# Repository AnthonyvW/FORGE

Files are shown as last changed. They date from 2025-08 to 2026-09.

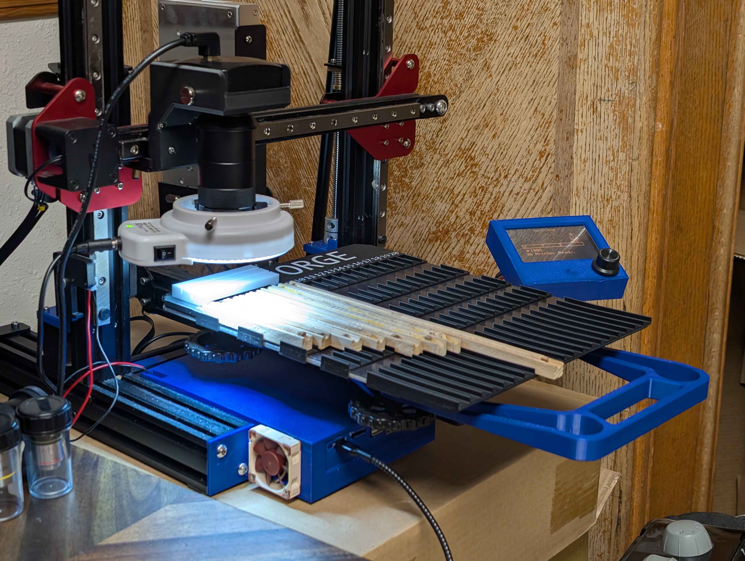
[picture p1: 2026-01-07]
media/DeveloperForge.jpg

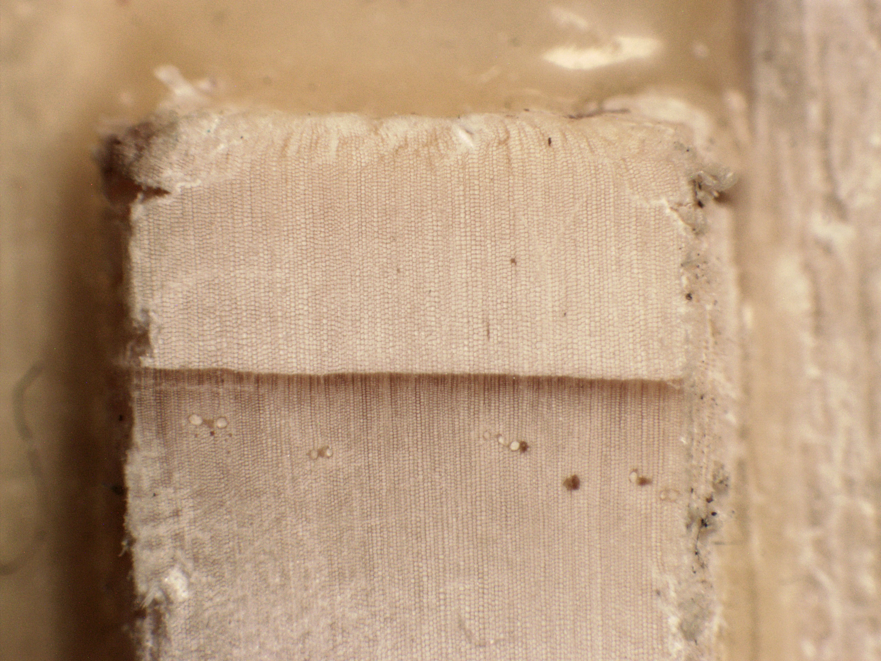
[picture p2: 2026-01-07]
media/WoodExample.jpg

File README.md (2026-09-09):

# FieldWeave - Low Cost Gigapixel Imaging Machine








FieldWeave is an open-source, gigapixel imaging system built on a modified off-the-shelf 3D printer. It automates sample capture, focus stacking, and DPI calibration, producing high resolution images across a wide range of fields. See it in action on the [FieldWeave website](https://www.fieldweave.com), which includes an interactive gallery for browsing full-resolution scans.

**If FieldWeave is useful to you, please consider giving it a star and supporting its development. See [Support FieldWeave](#support-fieldweave) below.**

## Features

* **Automated Scanning**: Utilizes 3D printer mechanics for precise, repeatable sample movement.
* **High-Resolution Imaging**: Captures gigapixel images across dendrochronology, geology, life sciences, museum, manufacturing, and forensic use cases.
* **Focus Stacking**: Built-in stacking via FocusWeave.
* **Automated DPI Calibration**: Calibrates scan resolution automatically against a compatible micrometer slide.
* **Modular Design**: Easily adaptable to different sample types, lenses, and imaging requirements.

## Examples

### [Browse the full gallery at fieldweave.com/gallery](https://www.fieldweave.com/gallery)

<table>
  <tr>
    <td width="33%">
      <a href="https://www.fieldweave.com/gallery/image/cross-section-1">
        Cross section of a black spruce tree core, click to view full resolution on the FieldWeave gallery
      </a>
    </td>
    <td width="33%">
      <a href="https://www.fieldweave.com/gallery/image/western-hemlock-core">
        Western hemlock tree core, click to view full resolution on the FieldWeave gallery
      </a>
    </td>
    <td width="33%">
      <a href="https://www.fieldweave.com/gallery/image/basswood-stem-cs">
        Cross section of a basswood stem, click to view full resolution on the FieldWeave gallery
      </a>
    </td>
  </tr>
	<tr>
    <th>Black spruce tree core cross section</th>
    <th>Western hemlock tree core</th>
    <th>Basswood stem cross section</th>
	</tr>
  <tr>
    <td width="33%">
      <a href="https://www.fieldweave.com/gallery/image/rusty-7-16-drill-bit">
        A rusty 7/16 drill bit, click to view full resolution on the FieldWeave gallery
      </a>
    </td>
    <td width="33%">
      <a href="https://www.fieldweave.com/gallery/image/us-dime-back">
        Back of a US dime, click to view full resolution on the FieldWeave gallery
      </a>
    </td>
    <td width="33%">
      <a href="https://www.fieldweave.com/gallery/image/9mm-1">
        Spent 9mm bullet casing, click to view full resolution on the FieldWeave gallery
      </a>
    </td>
  </tr>
	<tr>
    <th>A rusty 7/16 drill bit</th>
    <th>Back of a US dime</th>
    <th>Spent 9mm bullet casing</th>
	</tr>
</table>

## Support FieldWeave

FieldWeave is free and GPL-licensed, and stays that way through community support. If it's useful to your lab, workflow, or project, consider chipping in. Funding goes directly toward hardware, testing, and development time.

* **GitHub Sponsors**: [github.com/sponsors/AnthonyvW](https://github.com/sponsors/AnthonyvW)
* **Ko-fi**: [ko-fi.com/procerand](https://ko-fi.com/procerand)

Have a specific feature your lab needs? [Commission a feature](https://www.fieldweave.com/contact) it gets built for you and becomes available to everyone.

## Getting Started

### Prerequisites

* **Hardware**: A [compatible 3D printer](#3d-printer-compatibility) modified for imaging purposes, a light, and a [compatible camera](#confirmed-compatible-cameras). The 3D printer may also require an additional cable to connect your PC to the printer. Note that this modification will likely void the warranty if you disconnect any cables, so test the 3D printer to ensure the motion system works before doing this.
  * For the light I recommend using the [Amscope 144 led ring light](https://www.amazon.com/dp/B00JZJO7YC). If you use this, make sure to 3D print the light pads to prevent scratching the lens.
  * If using an Amscope camera, I highly recommend using this ([100x Microscope Lens for Raspberry Pi](https://www.amazon.com/100X-Microscope-Lens-Magnification-Compatible/dp/B0C1CC79TX)) industrial lens as it provides minimal distortion around the edges.
  * Not required, but is recommended is a thumbscrew for holding the camera in place. I use thumbscrews from [this 16 piece set](https://www.amazon.com/dp/B0DQPM68KJ) from Amazon.
  * For the automated DPI calibration to work, a compatible micrometer calibration slide is required. It is confirmed to work with the [Amscope MR400 Stage Micrometer Calibration Slide with 4-Scales](https://amscope.com/products/mr400). I am interested in adding support for additional scales.
  * If you do not have access to a 3D printer capable of printing in at least 2 colors and wish to image tree core samples, then a roll of red electrical tape to denote the center of slots.
* **High Magnification Imaging Hardware**
  * Note: This is a more expensive version that achieves far greater magnification than most other setups, however it requires additional modifications. Instead of using the 100x lens listed above, use the following parts instead for the optics.
  * To successfully do this version with 10x objective it will require upgrading the leadscrews to [350mm Tr8X2 2mm lead](https://www.amazon.com/dp/B095M8SQQV?th=1) with the appropriate [anti backlash nuts](https://www.amazon.com/dp/B085GGMCVG?th=1)
  * For the tube lense I recommend using the [Raynox DCR 250 Lens](https://www.amazon.com/Raynox-DCR-250-Super-Macro-Snap/dp/B000A1SZ2Y/) as there are 3D models present that use that.
  * [M49 to RMS Adapter](https://www.amazon.com/dp/B0FHN8FQ7T) for connecting the microscope objective to the tube lens
  * [C Mount to M42 Adapter](https://www.amazon.com/dp/B0812QPHWN) for connecting the camera to the high magnification setup.
  * For the high magnification setup, 1/4" thumbscrews are required to hold the camera in place. I use thumbscrews from [this 16 piece set](https://www.amazon.com/dp/B0DQPM68KJ) from Amazon.
  * For the microscope objective I recommend either the [Amscope 4x Metallurgic objective](https://amscope.com/products/pl4x-inf-v300) or the [Amscope 10x metallurgic objective](https://amscope.com/products/pl10x-inf-v300) both objectives are infinity plan achromatic objectives. Using anything above 10x is not recommended due to the depth of field becoming shallower than what the machine is capable of moving.
  * Due to the depth of the holes on the 3D printed parts I recommend getting a set of longer than usual metric hex keys so you can screw everything in properly. I use [this set.](https://www.amazon.com/dp/B0000CBJDV) 
* **Software**: Python 3.x and Git
* **Operating System**: Linux, Windows 10, or Windows 11

## Printer Modification

Before using FieldWeave, your 3D printer must be modified to mount the camera system in place of the print head.

### Required Printed Parts

Before modifying your printer, you must 3D print the following components:

- **Camera Mount** - Ender 3 Camera Mount.3mf – Attaches to the existing print head carriage  
- **High Resolution Camera Mount Files** - high_magnification folder
  * These are only for if you are going with the high magnification version of FieldWeave.
  * MicroscopeObjectiveMount.3mf - Attaches to print head carriage
  * Light Baffles.3mf - Insert to objective mount after screwing the mount in.
  * Amscope Mount.3mf - Attaches to the print head carriage to hold camera in place
  * RaynoxRingLightBuffer.3mf - Use if using the amscope ring light with it. You will need 3 of these. These help hold the ring light still.
- **Z-Axis Spacer** - ZAxisSpacer.3mf – Raises the Z-axis endstop to accommodate the new camera height  
    - If you are proficient with working with electronics, I suggest replacing the Z axis end stop wires with longer ones instead and mounting the Z axis limit switch higher.

> files for these parts will be provided in the `hardware/` folder of this repository.

### Optional Printed Parts
- **Calibration Slide Tray** - If using a micrometer calibration slide, this tray holds it stationary on the bed of the machine while providing a solid colored background.
- **Sample Clips** – Secure tree core samples to the print bed without manual alignment
    - SampleHolderEnd.3mf
    - SampleHolderFooter.3mf - If printing the multicolor version ensure that all the tick marks are printed in a red filament.
    - SampleHolderMiddle.3mf - You will need 3 of these. I suggest printing one of these off and ensuring that it properly fits before printing off the rest of the parts.
---

### Modification Instructions

> ! IMPORTANT ! Ensure that you have all 3D printed parts before modifying your 3D printer.

1. **Unplug 3D Printer**  
   Ensure the 3D printer is disconnected from power before working on it.

2. **Remove the Print Head**  
   Unscrew and detach the printer's hotend from the X-axis print carriage.

3. **Disconnect Wiring**  
   Carefully disconnect the hotend and heatbed wiring from the printer's control board. This prevents accidental heating or movement of the removed components.

4. **Install Camera Mount**  
   Use the print head screws to attach the printed camera mount to the same location on the print carriage where the print head was originally mounted.

5. **Insert Z-Axis Spacer**  
   Add the printed Z-axis spacer on the Z endstop, so the camera does not crash while homing.

6. **Insert sample clips**
   If you choose to use sample clips then this is the stage where you would want to slide them onto the print bed. If you printed the footer in single color you will also want to mark the center of the slots (above the slot not in the slot) with a red mark. I recommend using red electrical tape as it doesn't fade.

7. **Install Camera and Lens**  
   - Insert your digital microscope or Amscope camera into the printed mount.  
   - Screw on the imaging lens securely.  
   
8. **Install Light**  
   Install the light you will be using with FieldWeave. 
   > If using the Amscope ring light, place the light pads onto the metal tips of the screws that hold the light in place before putting the light on the lens.

9. **Plug Everything in**  
   - Plug the 3D printer back into the wall
   - Plug the 3D printer into your computer via USB for motion control.  
   - Plug in the camera using its USB interface for image capture.
   - Plug in the Light

10. **Done**

### Installation

Prerequisites\. Ensure you have the latest version of python installed, and you have git installed.

> Python : https://www.python.org/downloads/  
> Git : https://git-scm.com/downloads

1\. Clone the repository:

   ```bash
   git clone https://github.com/AnthonyvW/FieldWeave.git
   cd FieldWeave
   ```

2\. Install the required Python packages:

  ```bash
  pip install -r requirements.txt
  ```

3\.1\. Download the Amscope SDK for your camera at https://amscope.com/pages/software-downloads if you are on mac or linux, download the windows version as it includes the files for those operating systems there.

3\.2\. Move the downloaded zipped folder into 3rd_party_imports

4\. Run the install scripts:

  Windows
  ```bash
  windows_install.bat
  ```
  Linux
  ```bash
  ./ubuntu_install.sh
  ```
5\. Start FieldWeave

  Windows
  ```bash
  windows_start.bat
  ```
  Linux
  ```bash
  ./ubuntu_start.sh
  ```

---
## Confirmed Compatible Cameras
FieldWeave supports USB cameras through a modular driver architecture.

| Camera Model | Notes |
|---|---|
| Amscope MU500 | Fully tested and supported  |
| Amscope MU1000 | Fully tested, the automatic DPI calibration might not work due to it being tested at a lower resolution than this camera's max resolution |
| Amscope MU1000 HS | Fully tested, the automatic DPI calibration might not work due to it being tested at a lower resolution than this camera's max resolution |
| Generic USB Camera | This was tested with 2 different USB cameras and is supported  |
| Other Amscope Cameras | They should work, but are not tested. Camera mount might need to be modfied for them to fit. |

⚠️ Amscope's SDK on their website is currently out of date as of 8/15/2026. If you contact Amscope support an up to date version can be provided. The SDK version I use is Version: 59.30149.20251130

### Adding Support for New Cameras

Users are encouraged to contribute new camera interfaces by implementing the FieldWeave camera interface and submitting them as pull requests.

If your camera is not currently supported or you would like to contribute an interfaces, please open an issue or submit a pull request.

Due to the complexity of hardware integration, especially with cameras requiring proprietary APIs or SDKs full support often requires physical access to the device for development and testing. If you would like me to implement support for your camera, please be prepared to ship the device or provide access to equivalent hardware.

Alternatively, contributions of driver implementations with thorough documentation and test instructions are highly appreciated.

## 3D Printer Compatibility

FieldWeave is designed to run on 3D printers using **Marlin firmware**, which supports standard G-code over USB serial. Compatibility with other firmware types varies and may require additional configuration or is not currently supported.

> Not sure if your 3D printer will work? Plug your printer into your computer via USB, and then start FieldWeave. If the printer homes then it is compatible with FieldWeave.

## Confirmed Compatible Printers

| Printer Model | Firmware | Build Volume (mm) | Notes |
|---|---|---|---|
| Ender 3 v1 | Marlin | 220 × 220 × 250 | Fully tested and supported. It is highly recommended that you use the official linear rail upgrade kit provided by Creality for the increased camera stability. |
| Creality CR-10S Pro v2  | Marlin | 300 × 300 × 400 | Fully tested; camera mount file not available. |
| Anycubic Kobra Max v1 | Marlin | 400 × 400 × 450 | Fully tested; camera mount file not available. |
---

> Want to help verify compatibility with other printers, firmware, or cameras?  
> [Open an issue](https://github.com/AnthonyvW/FieldWeave/issues) with your setup details and test results!

## Confirmed Incompatible Printers

| Printer Model | Build Volume (mm) | Notes |
|---|---|---|
| Bambulab A1 | 220 × 220 × 250 | Properietary Firmware, cannot send gcode directly to it  |

---

## Contributing

Contributions are welcome! Please fork the repository and submit a pull request with your enhancements. For major changes, open an issue first to discuss your proposed modifications.

Not able to contribute code? Financial support is just as valuable; see [Support FieldWeave](#support-fieldweave) above ([GitHub Sponsors](https://github.com/sponsors/AnthonyvW) / [Ko-fi](https://ko-fi.com/procerand)).

## Troubleshooting

**Camera freezes when taking pictures**
- Sometimes the serial drivers conflict with the camera drivers, to fix this, plug in the camera and the 3D printer into two different sides of the computer. This forces them to be on different usb controllers which fixes any conflicts they might have.

**My Camera isn't found**
- Make sure that you have the camera drivers installed. If your camera was previously found, but is no longer found, try unplugging it and plugging it back in and ensuring the OS detects that it is plugged in as it might be a bad cable.

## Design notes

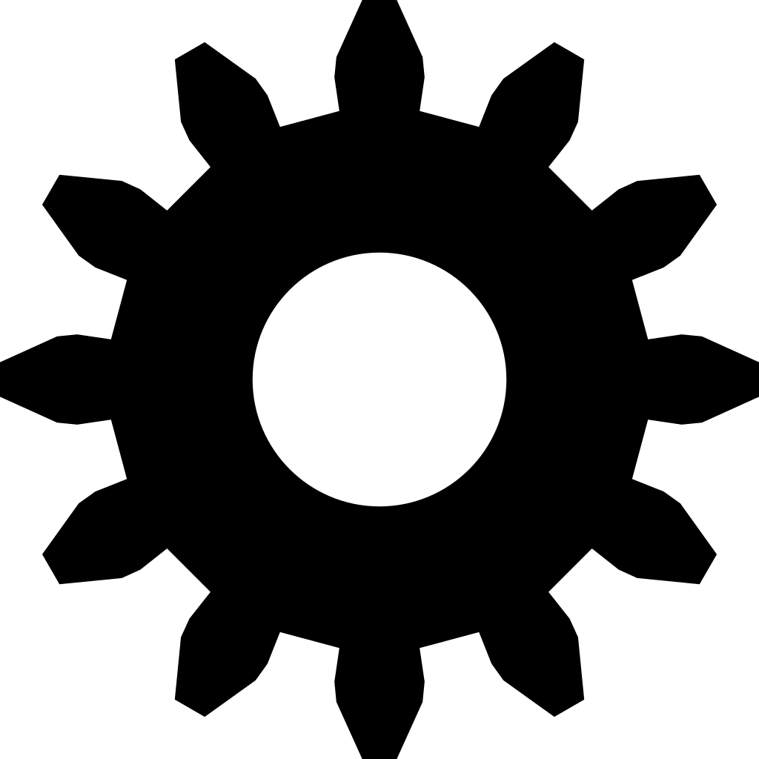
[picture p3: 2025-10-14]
assets/gear.png

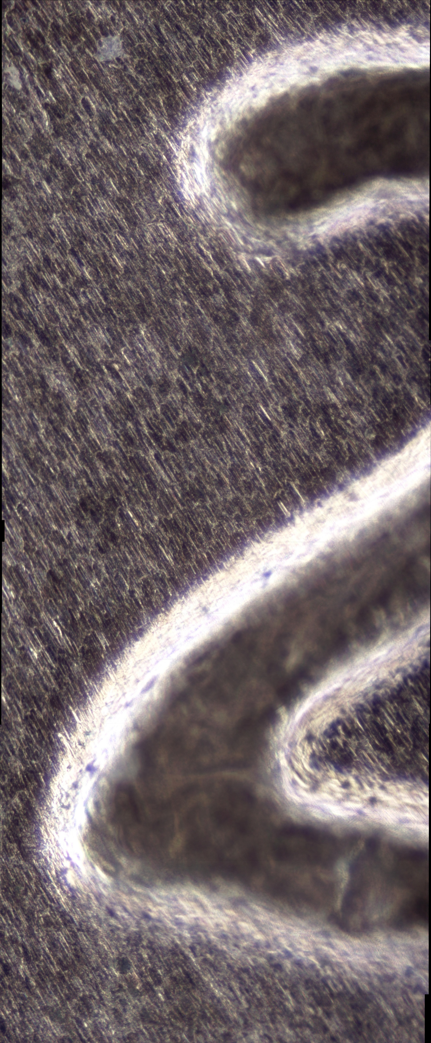
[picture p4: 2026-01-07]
media/2Penny.jpg

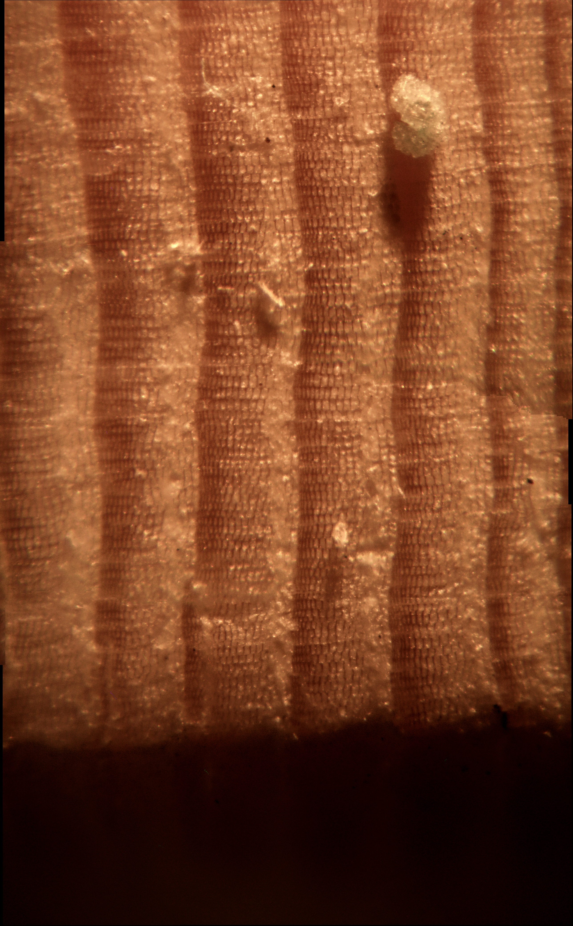
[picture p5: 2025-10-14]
media/Dust.jpg

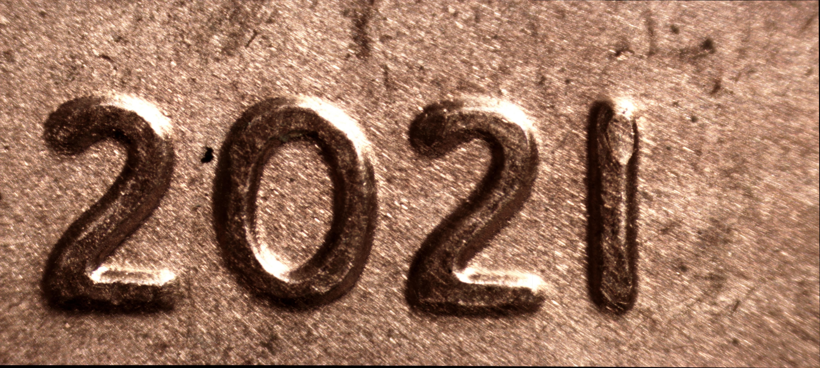
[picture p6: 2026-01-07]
media/penny.jpg

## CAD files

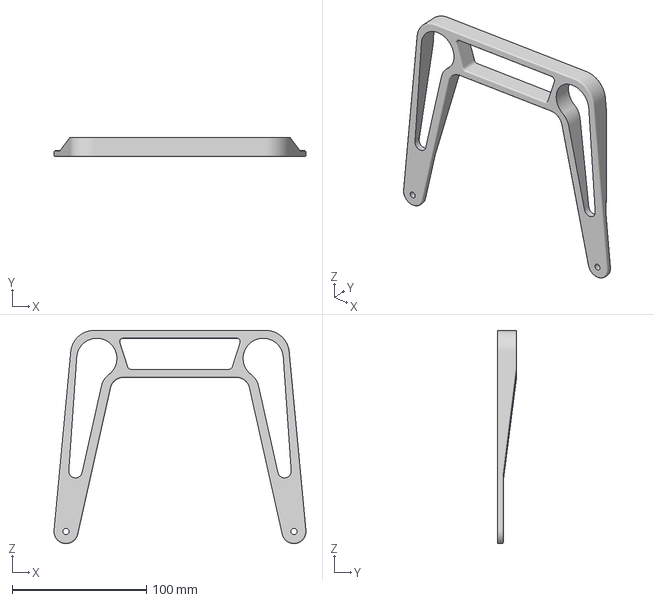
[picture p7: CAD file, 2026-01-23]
hardware/handle.3mf
187.9 x 14.5 x 159.0 mm

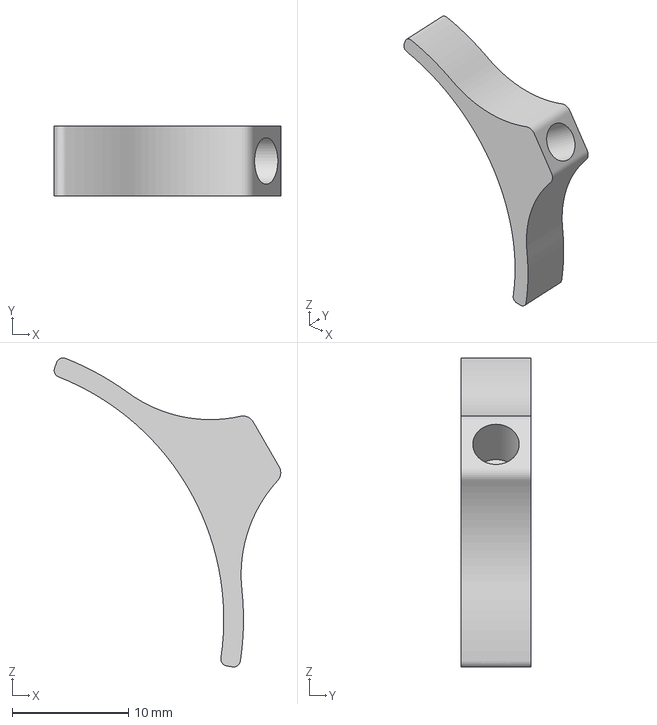
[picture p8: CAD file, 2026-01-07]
hardware/high_magnification/RaynoxRingLightBuffer.3mf
19.5 x 6.00 x 26.6 mm

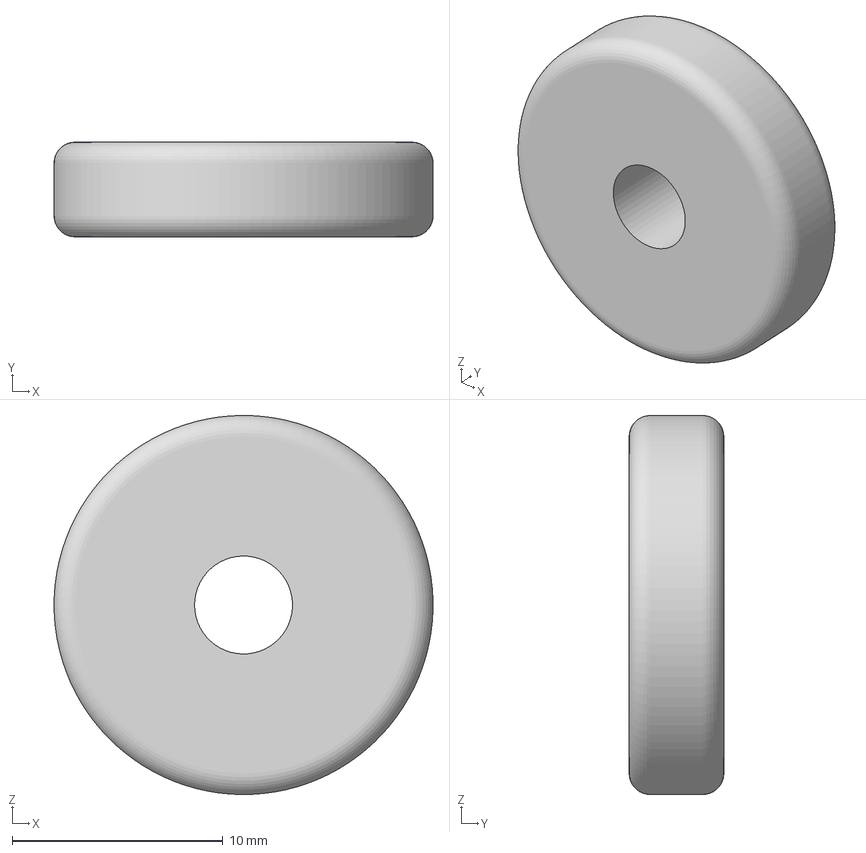
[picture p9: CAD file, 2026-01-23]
hardware/bedspacer.3mf
18.0 x 4.50 x 18.0 mm

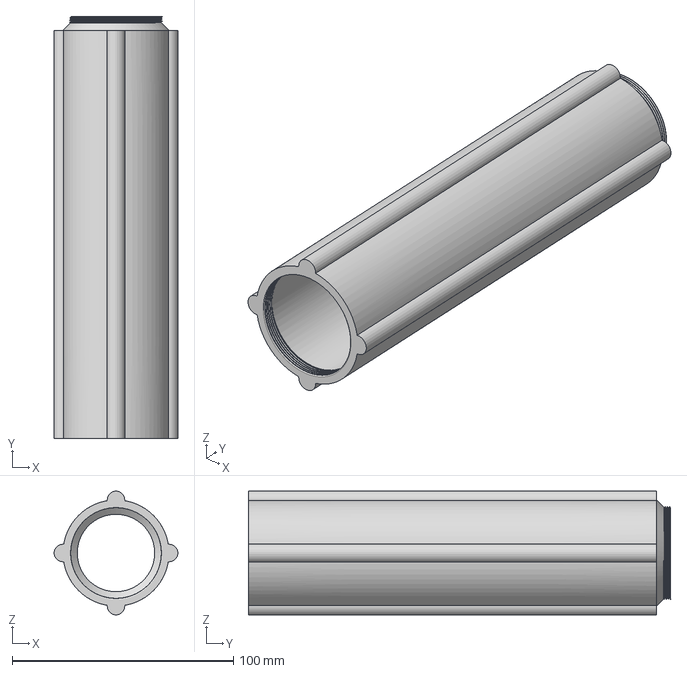
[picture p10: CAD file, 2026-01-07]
hardware/high_magnification/200mmExtensionTube.3mf
55.9 x 190.9 x 55.9 mm

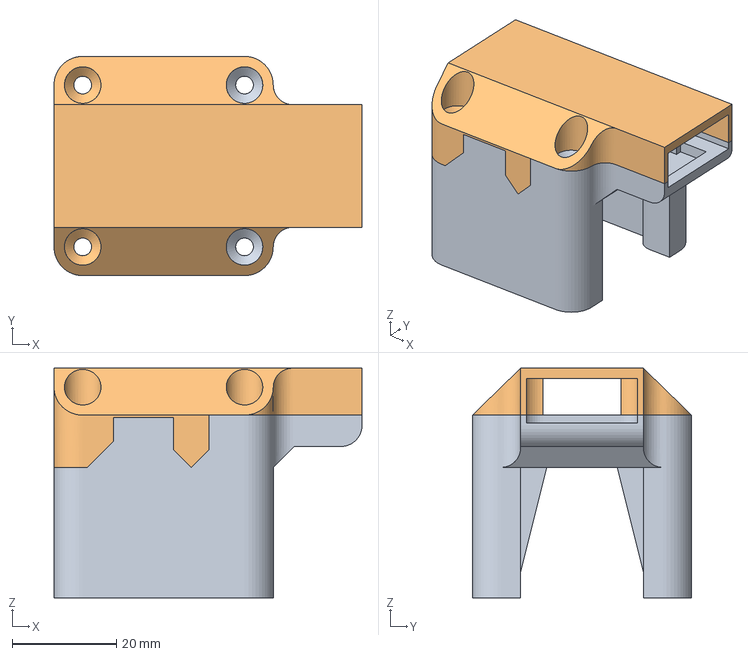
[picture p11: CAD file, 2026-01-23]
hardware/X Axis Motor Cover.3mf
59.0 x 42.0 x 44.0 mm

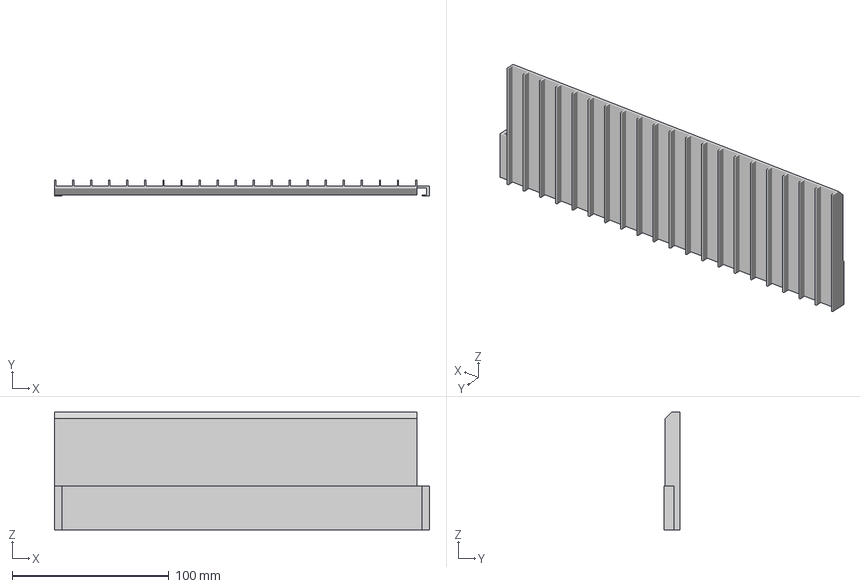
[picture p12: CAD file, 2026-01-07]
hardware/SampleHolderEnd.3mf
239.0 x 10.3 x 75.0 mm

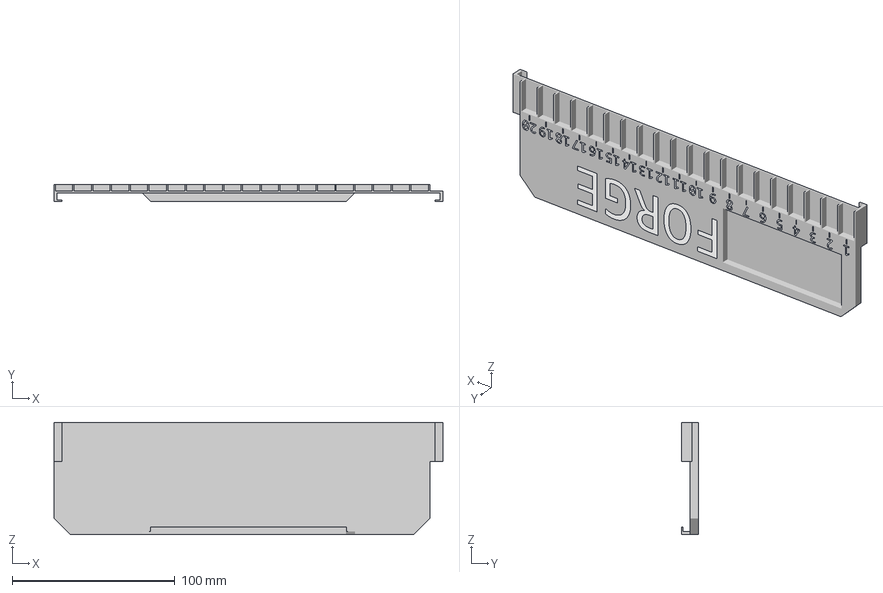
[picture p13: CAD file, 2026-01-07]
hardware/SampleHolderFooterMultiMaterial.3mf
239.0 x 10.3 x 69.0 mm
SampleHolderFooter

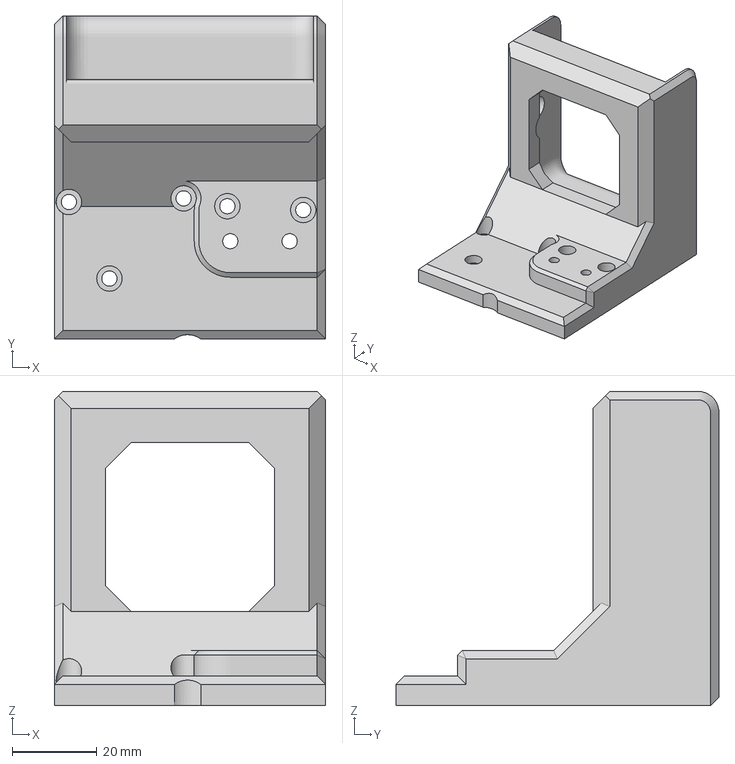
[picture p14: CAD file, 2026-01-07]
hardware/Ender 3 Camera Mount.3mf
64.0 x 76.1 x 74.1 mm

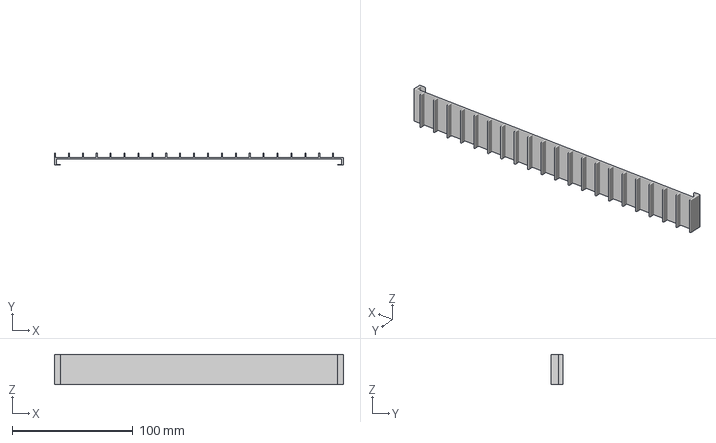
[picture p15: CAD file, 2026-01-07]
hardware/SampleHolderMiddle.3mf
239.0 x 10.3 x 25.0 mm

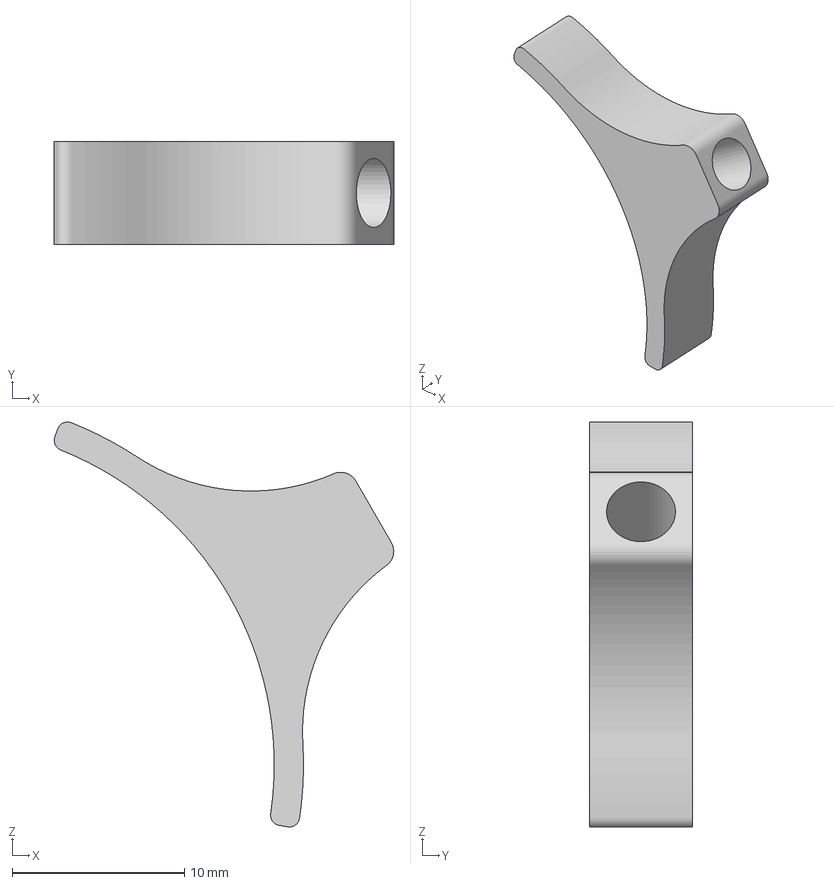
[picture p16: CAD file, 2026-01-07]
hardware/IndustrialLensRingLightPad.3mf
19.7 x 6.00 x 23.5 mm

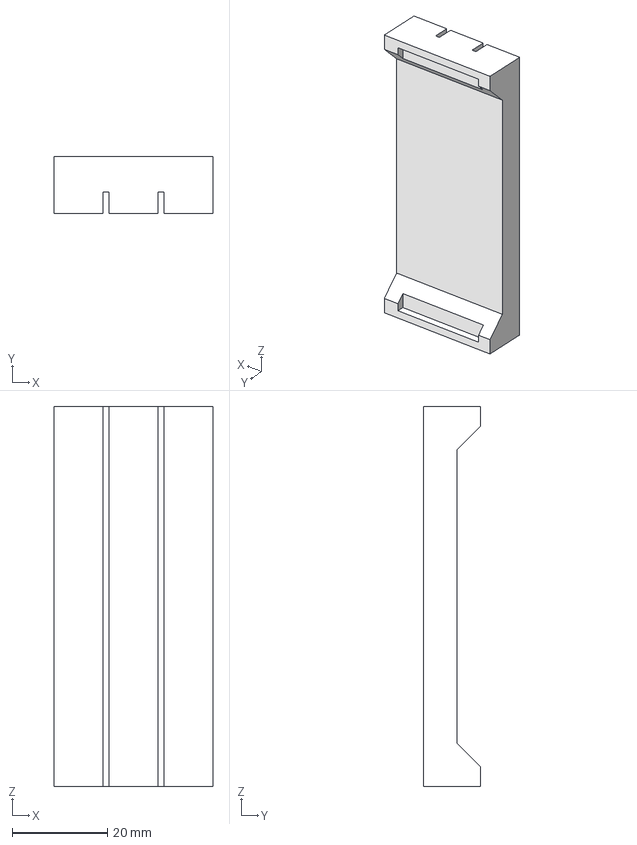
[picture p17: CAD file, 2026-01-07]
hardware/Calibration Slide Holder.3mf
33.3 x 12.0 x 79.6 mm

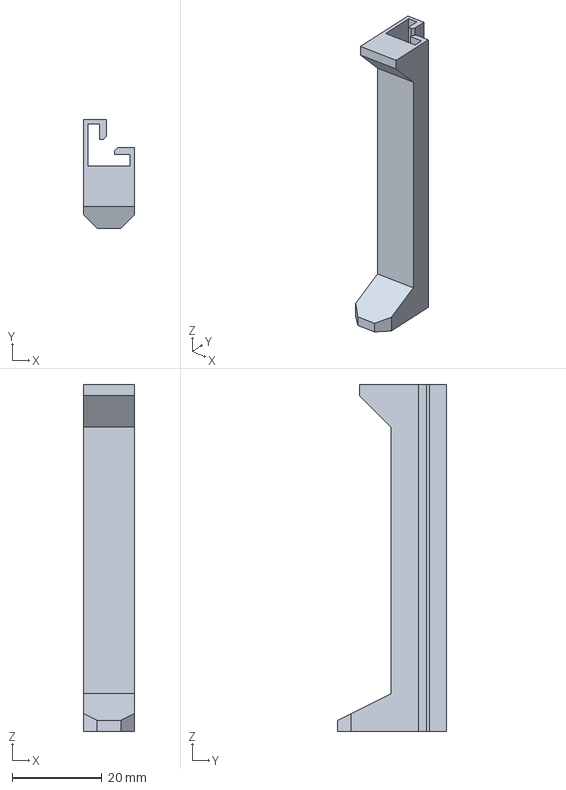
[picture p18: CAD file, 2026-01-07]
hardware/ZAxisSpacer.3mf
11.4 x 24.3 x 77.5 mm

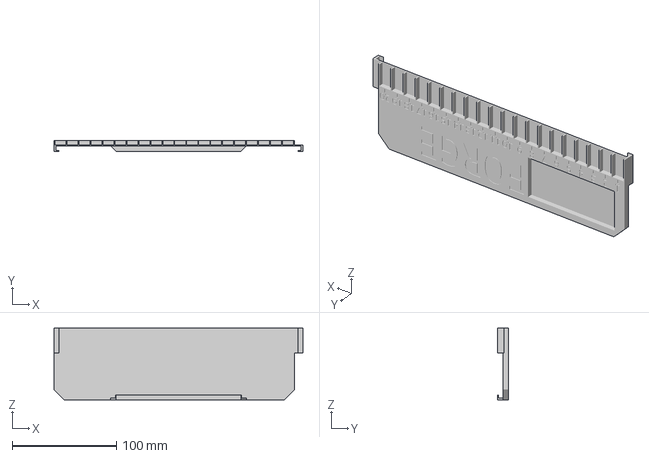
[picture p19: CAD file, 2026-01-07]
hardware/SampleHolderFooterSingleColor.3mf
239.0 x 10.3 x 69.0 mm

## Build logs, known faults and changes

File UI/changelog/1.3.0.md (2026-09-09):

# What's Changed
---
FieldWeave now has a changelog! It will display after every update, if you miss it and want to view it again, you can do so in the about page in the settings by pressing the view changelog button. In addition, it now has released based updates, this allows there to be a changelog that can be viewed ahead of time. The most notable change in this update is the addition of the measurement tab allowing you to measure things in FieldWeave. This also includes manual DPI calibration built in so you no longer have to go to an external program to obtain the DPI of a given image. 

In the next major update, you can look forward to an overhaul of the focus stacking allowing you to use other programs, improvements to time estimates, and the long awaited built in image stitching for tree core samples. 

If you come across any bugs while using FieldWeave, have feedback, or just want to request new features, please send them to <contact@FieldWeave.com> or open an issue on Github at <https://github.com/AnthonyvW/FieldWeave/issues/new>

# New Features & Improvements
---
- Added patch number to versioning scheme
- Added patch notes pop up
- Added button to view patch notes in the about page in settings
- Can now use the arrow keys to navigate when zoomed in
- Focus stacked images now preserve image metadata
- Added Measurement Tab
    - Added image viewer capable of handling terapixel images
    - Added manual DPI calibration
    - Added 34 measurement types
    - Added 4 annotation options
- Added manual DPI calibration path in the DPI calibration tab. This is also now a fallback in case the automatic DPI calibration fails.
- Added way to cancel the DPI calibration and return to the calibration tab from the DPI calibration tab.
- Added way to cancel the camera space calibration and return to the calibration tab from the camera space calibration tab.
- If the DPI calibration routine or the automatic DPI calibration fails, it will no longer set the DPI.
- All automation routines now have a button to open the output folder when running.
- Added github link on about page.
- Switched to release based updates

# Bugfixes
---
- Version field in config files now successfully migrates and is saved
- Fixed the post processing manager creating a redundant config
- While developing it will no longer warn about failing to update.
- Toasts no longer throw errors if you close the program while one is active.
- Fixed Amscope cameras not saving all camera metadata.
- Fixed Tiff writer not saving metadata.
- Camera metadata now saves to the proper metadata fields.
- Fixed issue where occasionally when doing area scan imaging an image from the previous stack would end up in the next stack.

# Known bugs
---
- Automatic camera calibration fails when using a resolution of 5120x3840
- Automatic DPI calibration fails if slide isn't perfectly straight
- Automatic DPI calibration tends to fail when using high resolution imagery
- Logs tab becomes extremely laggy on long runs.

# Support FieldWeave
---
FieldWeave is free and open source, and stays that way through community support. If it's useful to your lab, workflow, or project, consider chipping in. Funding goes directly toward hardware, testing, and development time.

* **GitHub Sponsors**: [github.com/sponsors/AnthonyvW](https://github.com/sponsors/AnthonyvW)
* **Ko-fi**: [ko-fi.com/procerand](https://ko-fi.com/procerand)

Have a specific feature your lab needs or just want to give feedback? [Contact us through the contact form](https://www.fieldweave.com/contact) or email us at <contact@fieldweave.com>

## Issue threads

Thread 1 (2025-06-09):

GUI polish to match feature parity with TRIM

AnthonyvW, 2025-06-09:
This issue tracks the implementation of features required for FORGE to reach functional parity with the legacy TRIM software. These are essential usability improvements needed for the v1.0 release.

**Tasks:**

- [x] Add ability to save, load, and export settings from the GUI
- [x] Add option to set custom save path for images
- [x] Add field to manually enter core length
- [x] Add option to set filename prefix
- [x] Add option to choose image format (PNG, JPEG, TIFF)
- [ ] Add UI control to customize shift length
- [x] Add UI for modifying camera settings (exposure, gain, etc.)

Closed 2025-08-21.

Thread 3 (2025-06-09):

Design 3D printable core holders for easy alignment

AnthonyvW, 2025-06-09:
Currently, it's a bit of pain making sure the sample is straight enough, so having 3D printed core holders would make it super easy to make sure everything is aligned properly.

Closed 2025-08-21.

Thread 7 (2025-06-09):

Clean up GUI

AnthonyvW, 2025-06-09:
Right now, it is the definition of programmer UI. This issue will track when it finally doesn't look terrible.

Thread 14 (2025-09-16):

Cannot fully image 20th slot of Ender 3 Guides

AnthonyvW, 2025-09-16:
The 20th slot on the Ender 3 is half outside of the 235mm area that the ender 3 allows moving the X axis on, as such the guides need to be modified to allow imaging that slot.

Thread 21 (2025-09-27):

Modular Z axis spacer

AnthonyvW, 2025-09-27:
The Z axis needs to be different heights depending on lenses used and printer used, as such a modular spacer would be appreciated. Preferably one that does not require disassembling the printer like the current spacer does.

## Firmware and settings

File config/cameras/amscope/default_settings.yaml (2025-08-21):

# Camera configuration (values + ranges). Ranges mirror settings.py.
auto_expo: false

# Auto Exposure Target
exposure: 16
exposure_min: 16
exposure_max: 220

# White balance temperature
temp: 10794
temp_min: 2000
temp_max: 15000

# White balance tint
tint: 925
tint_min: 200
tint_max: 2500

# Level ranges (RGBA). Min/max apply per channel.
levelrange_low: [0, 0, 0, 0]
levelrange_high: [255, 255, 255, 255]
levelrange_min: 0
levelrange_max: 255

contrast: 10
contrast_min: -100
contrast_max: 100

hue: 0
hue_min: -180
hue_max: 180

saturation: 45
saturation_min: 0
saturation_max: 255

brightness: -3
brightness_min: -64
brightness_max: 64

gamma: 100
gamma_min: 20
gamma_max: 180

# White balance gains (R, G, B). Min/max apply per channel.
wbgain: [0, 0, 0]
wbgain_min: -127
wbgain_max: 127

sharpening: 48
sharpening_min: 0
sharpening_max: 500

# 0/1; range is discrete but included for completeness
linear: 1
linear_min: 0
linear_max: 1

curve: Polynomial
fformat: tiff

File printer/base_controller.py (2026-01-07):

from dataclasses import dataclass
from enum import Enum
from queue import Queue
from typing import Optional, Callable, List, Dict, Iterable
import serial
import serial.tools.list_ports
import time
import queue
import threading
import re

from .models import Position
from .printerConfig import (
    PrinterSettings,
    PrinterSettingsManager
)
from forgeConfig import (
    ForgeSettings,
)

def _probe_port(port_device, baud, indicators, request=b"M115\r\n", read_window_s=10, min_lines=3):
    """
    Try to identify a Marlin-like printer on a single serial port.
    Returns (serial_connection, response_lines) on success, or (None, response_lines) on failure.
    On success, the serial connection is LEFT OPEN for the caller.
    """
    responses = []
    ser = None
    success = False
    try:
        ser = serial.Serial(
            port_device,
            baudrate=baud,
            timeout=0.25,       # slightly less chatty spin
            write_timeout=1
        )

        # Some controllers reset on open due to DTR; give them a brief window to chatter.
        start = time.time()
        quiet_since = start
        while time.time() - start < 2.0:   # ~2s settle (exits earlier if quiet)
            while ser.in_waiting:
                line = ser.readline().decode("utf-8", errors="ignore").strip()
                if line:
                    responses.append(line)
                    quiet_since = time.time()
            if time.time() - quiet_since > 0.25:
                break
            time.sleep(0.05)

        # Ask for firmware info
        ser.reset_input_buffer()
        ser.write(request)

        # Read with a firm window
        start = time.time()
        while time.time() - start < read_window_s:
            if ser.in_waiting:
                line = ser.readline().decode("utf-8", errors="ignore").strip()
                if line:
                    responses.append(line)
                    if any(ind in line for ind in indicators):
                        success = True
                        break
                    # Heuristic: enough lines + a few seconds → likely the right device
                    if len(responses) >= min_lines and time.time() - start > 3:
                        success = True
                        break
            else:
                time.sleep(0.05)

        if success:
            return ser, responses  # leave open
        else:
            return None, responses
    except Exception:
        return None, responses
    finally:
        # Only close when NOT successful
        if ser is not None and ser.is_open and not success:
            try:
                ser.close()
            except Exception:
                pass


class PrinterFault(Exception): pass
class PrinterTimeout(Exception): pass

@dataclass
class command:
    kind: str 
    value: any
    message: Optional[str] = None   
    log: bool = False

class BasePrinterController:
    CONFIG_SUBDIR = "Ender3"
    """Base class for 3D printer control"""
    def __init__(self, forgeConfig: ForgeSettings):
        self.config = PrinterSettings()
        PrinterSettingsManager.scope_dir(self.CONFIG_SUBDIR)
        self.config = PrinterSettingsManager.load(self.CONFIG_SUBDIR)

        self.position = Position(0, 0, 0) # Current position
        self.speed = self.config.step_size  # Current Speed
        self.paused = False
        self.stop_requested = False
        self.faulted = False

        self.command_queue: Queue[command] = Queue()

        # Buffer for macros when paused.
        self._front_buffer: List[command] = []
        self._front_lock = threading.Lock()
        
        # Callbacks
        self._message_listeners: List[Callable[[str, bool, command], None]] = []
        self._handlers: Dict[str, Callable[[command], None]] = {}
        
        # register built-ins
        self.register_handler("PRINTER", self._handle_printer)
        self.register_handler("MACRO", self._handle_macro)
        self.register_handler("MACRO_WAIT", self._handle_macro)
        self.register_handler("STATUS", self._handle_status)


        # Initialize serial connection
        self._initialize_printer(forgeConfig)
        
        # Start command processing thread
        self._processing_thread = threading.Thread(target=self._process_commands, daemon=True)
        self._processing_thread.start()

    def _initialize_printer(self, forgeConfig):
        """Initialize printer serial connection"""
        baud = self.config.baud_rate
        indicators = getattr(self.config, "valid_response_indicators", None) or [
            "FIRMWARE_NAME", "Marlin", "Ender", "TF init", "echo:"
        ]

        # Ports list: configured (first) then all others (no duplicates)
        detected = [p.device for p in serial.tools.list_ports.comports()]
        if not detected:
            raise RuntimeError("No serial ports found. Is the printer connected?")

        preferred = []
        cfg_port = getattr(forgeConfig, "serial_port", None)
        if cfg_port:
            preferred = [cfg_port]
        remaining = [p for p in detected if p not in set(preferred)]
        ports_to_try = preferred + remaining

        print(f"Available ports (preferred first): {ports_to_try}")

        for dev in ports_to_try:
            try:
                label = "(configured)" if preferred and dev == preferred[0] else ""
                print(f"Trying port {dev} {label}".strip())
                ser, lines = _probe_port(
                    port_device=dev,
                    baud=baud,
                    indicators=indicators,
                    request=b"M115\n",
                    read_window_s=10,
                    min_lines=3,
                )
                if ser is not None:
                    self.printer_serial = ser  # keep open
                    print(f"Printer found on port: {dev}")
                    # show last few lines like old version
                    for ln in lines[-10:]:
                        print(f"[{dev}] {ln}")
                    return
                else:
                    print(f"Port {dev} did not respond as a compatible printer. Observed {len(lines)} line(s).")
            except Exception as e:
                print(f"Port {dev} failed: {e}")

        raise RuntimeError(f"Printer not found on any available serial port. Tried: {ports_to_try}")

    def _process_commands(self):
        time.sleep(1)
        self.home()
        while True:
            if self.paused:
                time.sleep(0.05)
                continue
            try:
                cmd = None
                with self._front_lock:
                    if self._front_buffer:
                        cmd = self._front_buffer.pop(0)
                if cmd is None:
                    cmd = self.command_queue.get()
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

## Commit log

2024-11-22 Added current progress
2024-11-27 Added resizable window and cleaned up camera
2024-11-27 Implemented Amscope Camera
2024-11-28 implemented 3D printer control
2025-02-16 fixed default controls and added framework for skipping images
2025-05-16 Added auto homing and port scanning
2025-06-23 readded accidentally removed camera wrapper
2025-07-18 added frames
2025-07-18 added sample positioning
2025-08-11 updated to account for printer dimensions
2025-08-11 uploaded hardware
    [Ender3AmscopeCameraMount.3mf, SampleHolderEnd.3mf, SampleHolderFooter.3mf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]
2025-08-12 updated readme, and implemented seeking in text fields
    [ZAxisSpacer.3mf]
2025-08-12 added visibility options to frames
2025-08-15 camera settings is no longer open by default
2025-08-15 refactored camera to use a frame
2025-08-21 added camera settings
2025-08-21 added camera file format setting
2025-08-21 camera settings actually update now
2025-08-21 finished camera settings
2025-08-24 fixed being able to move lower than minimum movement
    [base_controller.py]
2025-08-29 added Ender 3 specific hardware
    [SampleHolderEnd.3mf, SampleHolderFooter.3mf, SampleHolderMiddle.3mf]
2025-09-11 Forge can now start without a camera
2025-09-16 hardware update
    [SampleHolderEnd.3mf, SampleHolderFooter.3mf, SampleHolderMiddle.3mf]
2025-09-16 sample positions are now consistent with real positions
2025-09-23 added 3d printer config
2025-09-23 moved camera config into proper folder
2025-09-24 faster printer detection
2025-09-26 pause button pauses better
2025-09-26 Added status messages and fixed print bug
    [base_controller.py]
2025-09-26 pause button is back
2025-09-26 camera now updates when taking images
2025-09-26 added machine vision overlay button
2025-09-26 added toggle buttons and list frames
2025-10-03 Is now capable of scanning samples
2025-10-03 camera is now independent from the GUI
2025-10-08 Added script for updating Z axis
2025-10-08 can now use printer's full max bounds
2025-10-09 all 20 samples can now be used
2025-10-09 scroll frames can now scroll using mouse
2025-10-09 section frame bug fix and added padding
2025-10-09 button in scrollable area fix
2025-10-09 fixed printer not using config by default
    [base_controller.py, default_settings.yaml]
2025-10-21 camera now uses formatted names
2025-10-22 added button icons
2025-11-27 Updated hardware
    [200mmExtensionTube.3mf, Calibration Slide Holder.3mf, Ender3AmscopeCameraMount.3mf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]
2025-11-30 image stitching progress for y axis
2026-01-07 fixed issue where not being in absolute positioning messed stuff up
    [base_controller.py]
2026-01-07 new camera mount
    [Ender3CameraMount.3mf]
2026-01-07 expanded camera screw hole
    [Ender 3 Camera Mount.3mf, Ender3CameraMount.3mf]
2026-01-09 refactored the camera calibration
2026-01-09 Added Sample Slot Calibration Menu
2026-01-09 Calibration related changes
2026-01-23 updated some hardware
    [X Axis Motor Cover.3mf, bedspacer.3mf, handle.3mf]
2026-01-26 camera preview and logging
2026-01-29 Added Toasts and Camera Controls
2026-09-07 Allow dragging the manual DPI calibration line's endpoints
    The calibration line is tracked separately from ordinary measurements
    (_calibration_line, not self.measurements — it's never a real,
    exportable measurement), so hit_test_endpoint never found its points
    and every click on one just fell through to click-to-move/placement
    instead of grabbing it. Its two endpoints now participate in the same
    hit-test/drag path as any other measurement's, using measurement index
    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
2026-09-07 Re-sync measurement type when the Measurement tab regains the preview
    The overlay's active_type is separate state from MeasurementsWidget's
    selected tile — leaving the Measurement tab to do a manual DPI
    calibration elsewhere (e.g. the DPI Calibration wizard) resets it to
    None via cancel_calibration_placement, but the tile stays visibly
    selected here. Returning to the Measurement tab now re-applies the
    selected tile's kind on showEvent, instead of leaving placement a
    no-op until the user deselects/reselects a tile by hand.
    Claude-Session: https://claude.ai/code/session_01J6BHS2tvxPCgaHNyrggvZH
2026-09-09 Fixed automation using old frames
2026-09-09 Added open folder buttons for all automation routines.
2026-09-09 Fix X/Y DPI mismatch on rotated Amscope cameras
    get_current_still_resolution() returned the raw, unrotated
    width/height even when the camera's rotate setting is 90 or 270 -
    unlike get_still_output_dimensions(), which already swaps them to
    match the actual still buffer layout written by PullImageV4 in the
    EVENT_STILLIMAGE handler.
    CaptureControlWidget and the DPI Calibration wizard both feed this
    value straight into MeasurementOverlay.set_live_reference_dims(),
    which uses it to scale live-view measurement fractions into physical
    length. With rotation active, the swapped width/height transposed
    that scaling, so a horizontal measurement effectively used the
    sensor's vertical dimension and vice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
2026-09-09 Switched to release based updates
